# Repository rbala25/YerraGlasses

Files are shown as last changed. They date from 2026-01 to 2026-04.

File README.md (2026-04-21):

# YerraGlasses
 
Audio-augmented smart glasses that act as a wearable guide dog — real-time object detection converted to spatial audio feedback, all running on an ESP32-S3 tucked inside a glasses frame.
 
---
 
## Highlights
 
**Embedded ML Object Detection** — Neural network running on a **Luckfox RV1103 NPU** detects objects from live visual input and converts them into real-time auditory cues. Designed to assist blind and visually impaired users without any cloud dependency.
 
**Dual I2S Class-D Audio** — Two Class-D amplifiers driven over I2S deliver low-latency directional audio feedback. Custom DAC and speaker amplification stages built discrete, with 26-gauge wire crimped and routed by hand to fit the form factor.
 
**Space-Constrained PCB** — Custom board designed to fit inside a glasses frame. Integrates USB-C input, rail regulation, I2C sensor communication, and the full I2S audio pipeline — all in a footprint small enough to wear.
 
**Power System** — Robust battery management with USB-C charging, regulated power rails, and firmware-level power state detection to maximize battery life in a miniature form factor.
 
---
 
## Stack
 
| Layer | Tech |
|---|---|
| MCU | ESP32-S3 |
| Language | C, bare-metal |
| ML Inference | Luckfox RV1103 NPU (object detection) |
| Audio | Dual I2S Class-D amps + custom DAC |
| Communication | I2C |
| Power | USB-C + regulated rails + battery monitoring |
| Hardware | Custom PCB, 26-gauge hand-crimped wiring |

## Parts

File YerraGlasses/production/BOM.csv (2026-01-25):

Reference | Qty | Value | DNP | Exclude from BOM | Exclude from Board | Footprint | JLCPCB # | Mouser # | Mouser Link | Mouser Part Number
C1,C2,C15 | 3 | 4.7u |  |  |  | Capacitor_SMD:C_1206_3216Metric_Pad1.33x1.80mm_HandSolder | C513768 | 187-CL31A475KBHNNNE | https://www.mouser.com/ProductDetail/Samsung-Electro-Mechanics/CL31A475KBHNNNE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 | 187-CL31A475KBHNNNE
C3,C6,C7,C10,C11 | 5 | 100n |  |  |  | Capacitor_SMD:C_0603_1608Metric_Pad1.08x0.95mm_HandSolder | C14663 | 581-KAM15BR72A104KT | https://www.mouser.com/ProductDetail/KYOCERA-AVX/KAM15BR72A104KT?qs=Jm2GQyTW%2Fbivdeq3a3Ovhw%3D%3D | 581-KAM15BR72A104KT
C4,C8 | 2 | 10u |  |  |  | Capacitor_SMD:C_0805_2012Metric_Pad1.18x1.45mm_HandSolder | C440198 | 81-GRM21BR61H106KE3L | https://www.mouser.com/ProductDetail/Murata-Electronics/GRM21BR61H106KE43L?qs=lYGu3FyN48cBZlIduWKclg%3D%3D | 81-GRM21BR61H106KE3L
C5,C9 | 2 | 22u |  |  |  | Capacitor_SMD:C_0603_1608Metric_Pad1.08x0.95mm_HandSolder | C59461 | 963-A168BB5226MTNA01 | https://www.mouser.com/ProductDetail/TAIYO-YUDEN/MSASA168BB5226MTNA01?qs=efUn273yAhczomwMiufDyA%3D%3D | 963-A168BB5226MTNA01
D5 | 1 | SP3205-01ETG |  |  |  | 0_LHRE_Footprints:SP320501ETG | C19829542 | 576-SP3205-01ETG | https://www.mouser.com/ProductDetail/Littelfuse/SP3205-01ETG?qs=vHuUswq2%252BswfNhVD4WkB%252BQ%3D%3D | 576-SP3205-01ETG
D6 | 1 | UDD32C05L01 |  |  |  | Diode_SMD:D_SOD-323 | C78440 | 603-UDD32C05L01 | https://www.mouser.com/ProductDetail/YAGEO/UDD32C05L01?qs=0lSvoLzn4L8%252BwWZ0DjbM%2FA%3D%3D | 603-UDD32C05L01
D20 | 1 | D_Schottky |  |  |  | Diode_SMD:D_PowerDI-123 | C177023 | 621-DFLS160-F | https://www.mouser.com/ProductDetail/Diodes-Incorporated/DFLS160-7?qs=gAIB%252Bn6SvSQZOTFja6ZMPQ%3D%3D | 726-BAT60AE6327
D32,D33 | 2 | Green |  |  |  | Diode_SMD:D_0603_1608Metric_Pad1.05x0.95mm_HandSolder | C5246833 | 604-APT1608LZGCK | https://www.mouser.com/ProductDetail/Kingbright/APT1608LZGCK?qs=6oMev5NRZMFGFINT%2FafRYg%3D%3D | 604-APT1608LZGCK
F1,F2 | 2 | 1A |  |  |  | Fuse:Fuse_0603_1608Metric_Pad1.05x0.95mm_HandSolder | C136329 | 504-TR-0603HV1-R | https://www.mouser.com/ProductDetail/Eaton-Electronics/TR-0603HV1-R?qs=xZ%2FP%252Ba9zWqa2z3F2%252BP4ViA%3D%3D | 504-TR-0603HV1-R
H1,H2 | 2 | MountingHole |  | Excluded from BOM |  | MountingHole:MountingHole_2.2mm_M2_custom
J1,J2,J3,J4,J5 | 5 | Conn_01x02_Pin |  |  |  | Connector_JST:JST_PH_B2B-PH-K_1x02_P2.00mm_Vertical | C131337 | 306-B2BPHKSLFSNPP | https://www.mouser.com/ProductDetail/JST-Commercial/B2B-PH-K-SLFSN?qs=cdbOS8ANM9AlozzPlOt72g%3D%3D | 306-B2BPHKSLFSNPP
J11 | 1 | USB_C_Receptacle_USB2.0_16P |  |  |  | 0_LHRE_Footprints:USB-C_2.0_Receptacle | C2982555 | 640-USB4105-GF-A | https://www.mouser.com/ProductDetail/GCT/USB4105-GF-A?qs=KUoIvG%2F9IlY%2FMLlBMpStpA%3D%3D | 640-USB4105-GF-A
JP1 | 1 | SolderJumper_2_Open |  | Excluded from BOM |  | Jumper:SolderJumper-2_P1.3mm_Open_RoundedPad1.0x1.5mm
R1,R2,R45 | 3 | 10k |  |  |  | Resistor_SMD:R_0603_1608Metric_Pad0.98x0.95mm_HandSolder | C25804 | 71-CRCW0603-10K-E3 | https://www.mouser.com/ProductDetail/Vishay/CRCW060310K0FKEA?qs=pAO1Z172M84BVnhDjtnsoQ%3D%3D | 71-CRCW0603-10K-E3
R8,R35,R46,R48 | 4 | 5.1k |  |  |  | Resistor_SMD:R_0603_1608Metric_Pad0.98x0.95mm_HandSolder | C23186 | 71-CRCW0603-5.1K-E3 | https://www.mouser.com/ProductDetail/Vishay-Dale/CRCW06035K10FKEA?qs=pfqtYUWm1IVbeSxo5oKU9A%3D%3D | 71-CRCW0603-5.1K-E3
R9 | 1 | 100k |  |  |  | Resistor_SMD:R_0603_1608Metric_Pad0.98x0.95mm_HandSolder | C14675 | 603-RC0603FR-07100KL | https://www.mouser.com/ProductDetail/YAGEO/RC0603FR-07100KL?qs=e1ok2LiJcmaihem8Va5%2Fsw%3D%3D | 603-RC0603FR-07100KL
R22 | 1 | 22 |  |  |  | Resistor_SMD:R_0603_1608Metric_Pad0.98x0.95mm_HandSolder | C23345 | 71-CRCW0603-22-E3 | https://www.mouser.com/ProductDetail/Vishay-Dale/CRCW060322R0FKEA?qs=WV2t1o5hSQVzBsSjdimT7Q%3D%3D | 71-CRCW0603-22-E3
SW1 | 1 | SW_SPDT |  |  |  | Button_Switch_SMD:SW_SPDT_PCM12 | C319020 | 611-PCM12SMTBR | https://www.mouser.com/ProductDetail/CK/PCM12SMTBR?qs=By6Nw2ByBD1OEOnWcdZb2g%3D%3D | 611-PCM12SMTBR
TP1 | 1 | bootloader |  | Excluded from BOM |  | TestPoint:TestPoint_Pad_1.0x1.0mm
TP2 | 1 | gndBootloader |  | Excluded from BOM |  | TestPoint:TestPoint_Pad_1.0x1.0mm
U1 | 1 | ESP32-S3-WROOM-1 |  |  |  | RF_Module:ESP32-S3-WROOM-1 | C2913199 | 356-ESP32S3WROOM1N16 | https://www.mouser.com/ProductDetail/Espressif-Systems/ESP32-S3-WROOM-1-N16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 | 356-ESP32S3WROOM1N16
U2,U3 | 2 | MAX98357A |  |  |  | Package_DFN_QFN:TQFN-16-1EP_3x3mm_P0.5mm_EP1.23x1.23mm | C910544 | 700-MAX98357AETE+T | https://www.mouser.com/ProductDetail/Analog-Devices-Maxim-Integrated/MAX98357AETE%2bT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 | 700-MAX98357AETE+T
U4 | 1 | RT9013-33GB |  |  |  | Package_TO_SOT_SMD:SOT-23-5 | C47773 | 835-RT9013-33GB | https://www.mouser.com/ProductDetail/Richtek/RT9013-33GB?qs=amGC7iS6iy%2FHaDkSgZH71g%3D%3D | 835-RT9013-33GB
U6 | 1 | R-78E5.0-1.0 |  |  |  | Converter_DCDC:Converter_DCDC_RECOM_R-78E-0.5_THT | C22371890 | 919-R-78E5.0-1.0 | https://www.mouser.com/ProductDetail/RECOM-Power/R-78E5.0-1.0?qs=T0XSgvH75d4EsZCU9I5HVA%3D%3D | 919-R-78E5.0-1.0

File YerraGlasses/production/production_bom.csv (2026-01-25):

Designator | Footprint | Quantity | Value | LCSC Part #
C1, C15, C2 | 1206 | 3 | 4.7u
C10, C11, C3, C6, C7 | 0603 | 5 | 100n
C4, C8 | 0805 | 2 | 10u
C5, C9 | 0603 | 2 | 22u
D20 | D_PowerDI-123 | 1 | D_Schottky
D32, D33 | 0603 | 2 | Green
D5 | SP320501ETG | 1 | SP3205-01ETG
D6 | D_SOD-323 | 1 | UDD32C05L01
F1, F2 | 0603 | 2 | 1A
J1, J2, J3, J4, J5 | JST_PH_B2B-PH-K_1x02_P2.00mm_Vertical | 5 | Conn_01x02_Pin
J11 | USB-C_2.0_Receptacle | 1 | USB_C_Receptacle_USB2.0_16P
R1, R2, R45 | 0603 | 3 | 10k
R22 | 0603 | 1 | 22
R35, R46, R48, R8 | 0603 | 4 | 5.1k
R9 | 0603 | 1 | 100k
SW1 | SW_SPDT_PCM12 | 1 | SW_SPDT
U1 | ESP32-S3-WROOM-1 | 1 | ESP32-S3-WROOM-1
U2, U3 | TQFN-16-1EP_3x3mm_P0.5mm_EP1.23x1.23mm | 2 | MAX98357A
U4 | SOT-23-5 | 1 | RT9013-33GB
U6 | Converter_DCDC_RECOM_R-78E-0.5_THT | 1 | R-78E5.0-1.0

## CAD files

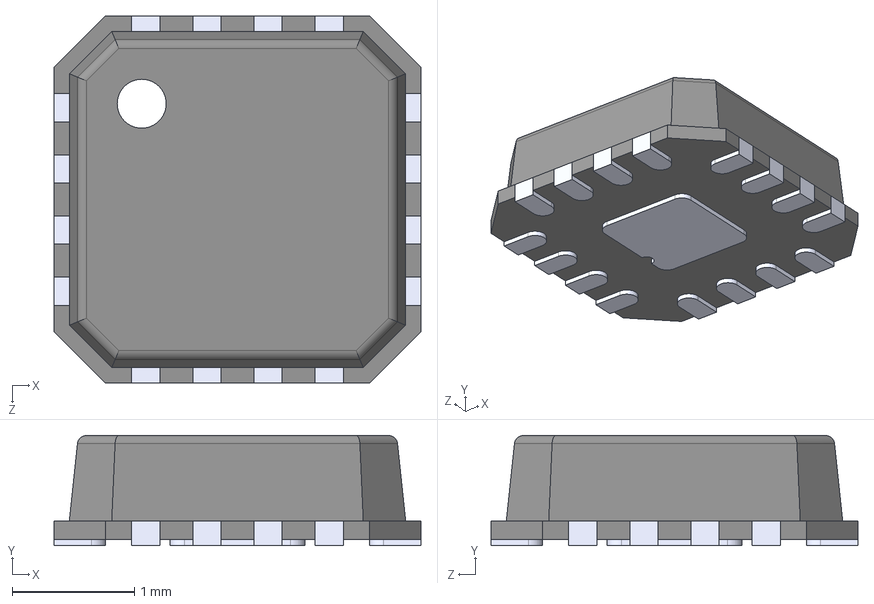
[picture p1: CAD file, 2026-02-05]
CAD/QFN50P300X300X80-17N.step
3.00 x 0.9 x 3.00 mm

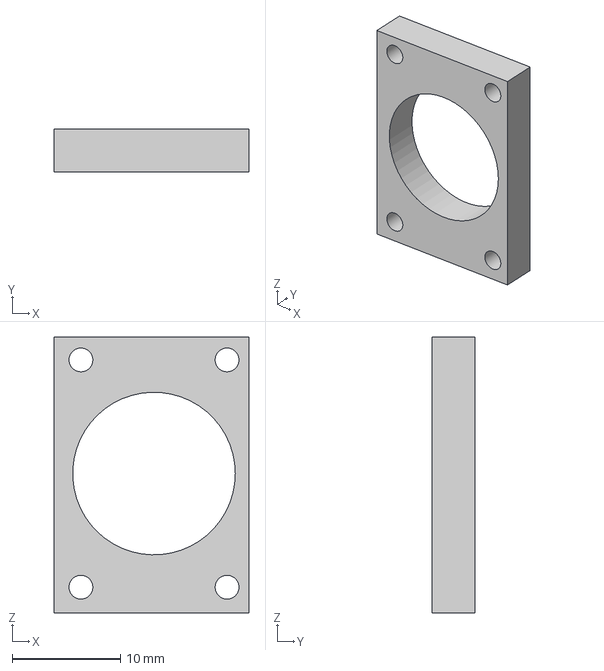
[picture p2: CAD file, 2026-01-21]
CAD/PrintableCameraMount.step
18.0 x 4.00 x 25.5 mm

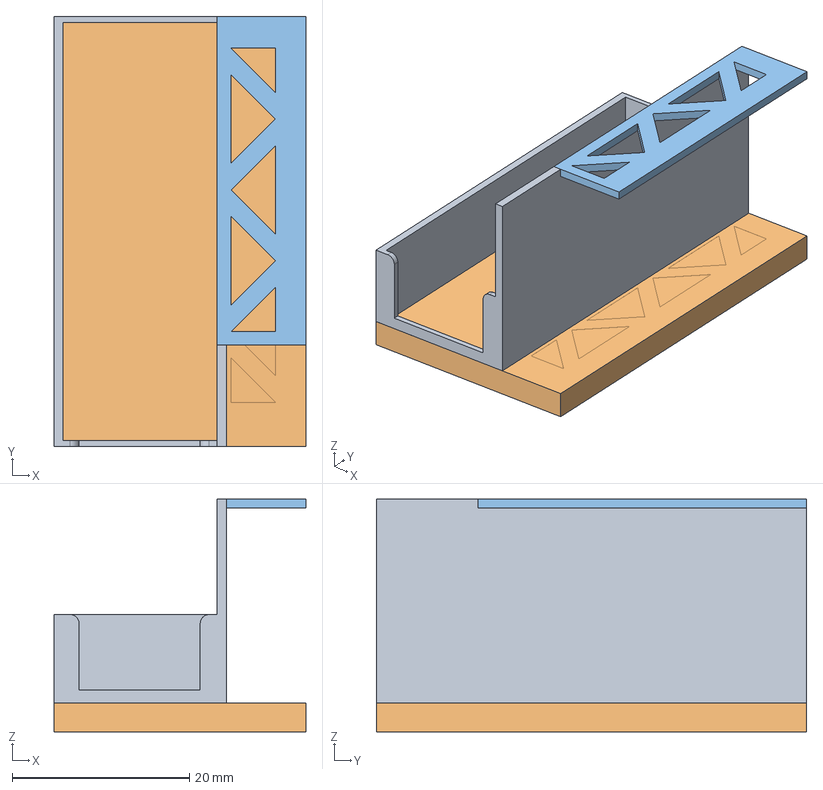
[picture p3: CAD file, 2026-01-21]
CAD/PrintableBatteryMount.step
28.4 x 48.6 x 26.3 mm

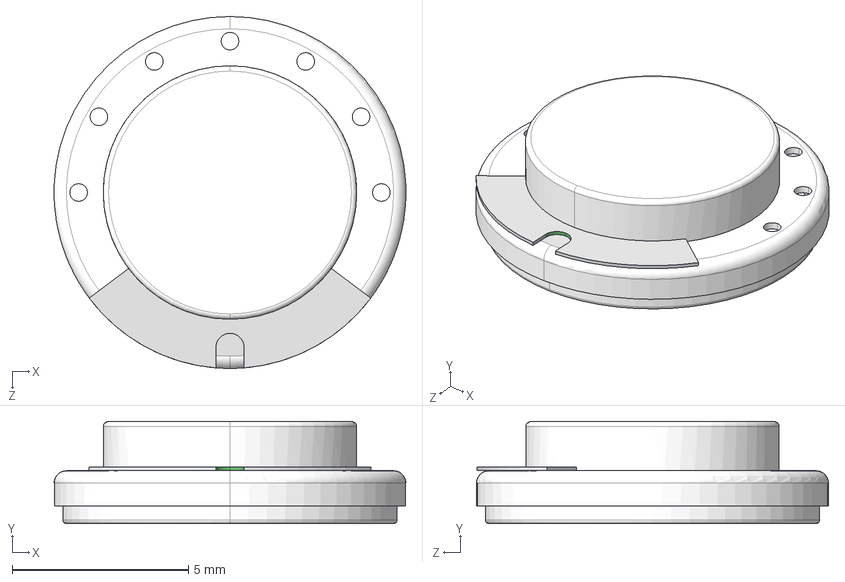
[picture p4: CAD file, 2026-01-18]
CAD/Same_Sky_CDM-10008.step
9.99 x 2.90 x 10.0 mm

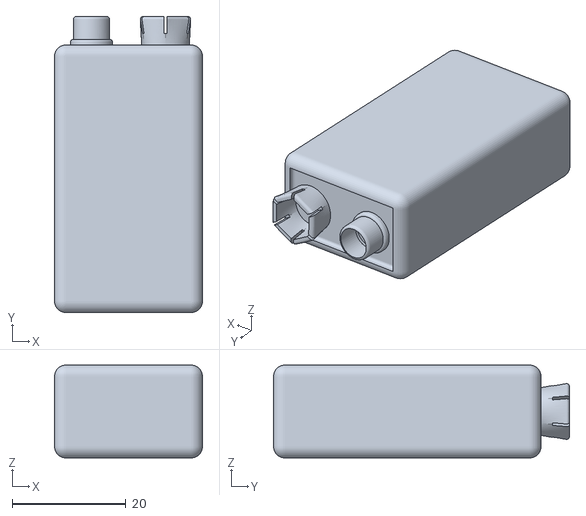
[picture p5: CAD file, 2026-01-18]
CAD/9V BATTRAY.STL
26.0 x 52.0 x 16.3

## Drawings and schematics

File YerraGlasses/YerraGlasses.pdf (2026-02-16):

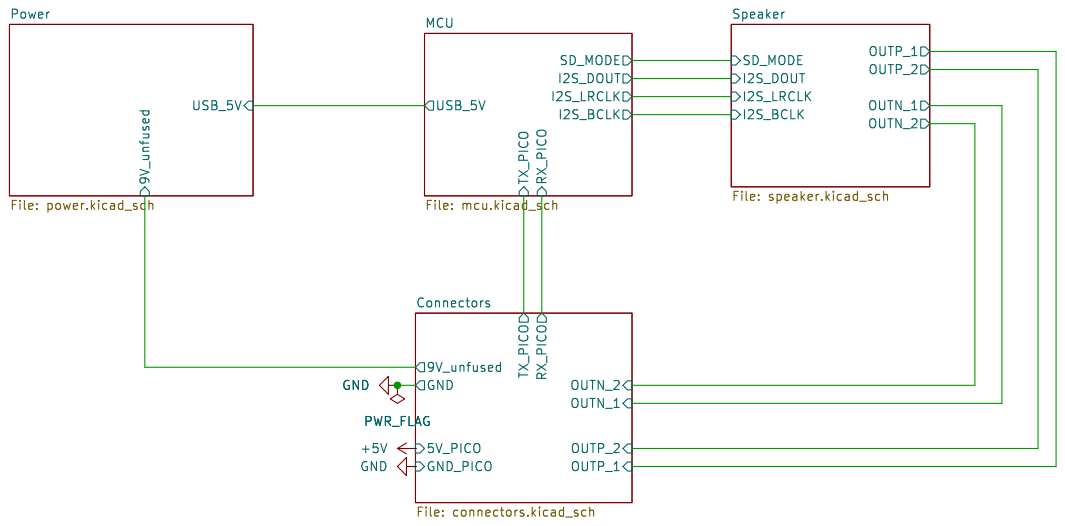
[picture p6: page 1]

Speaker File: speaker.kicad_sch GND
I2S_BCLK MCU

Id: 1/5 Title: File: YerraGlasses.kicad_sch Sheet: /

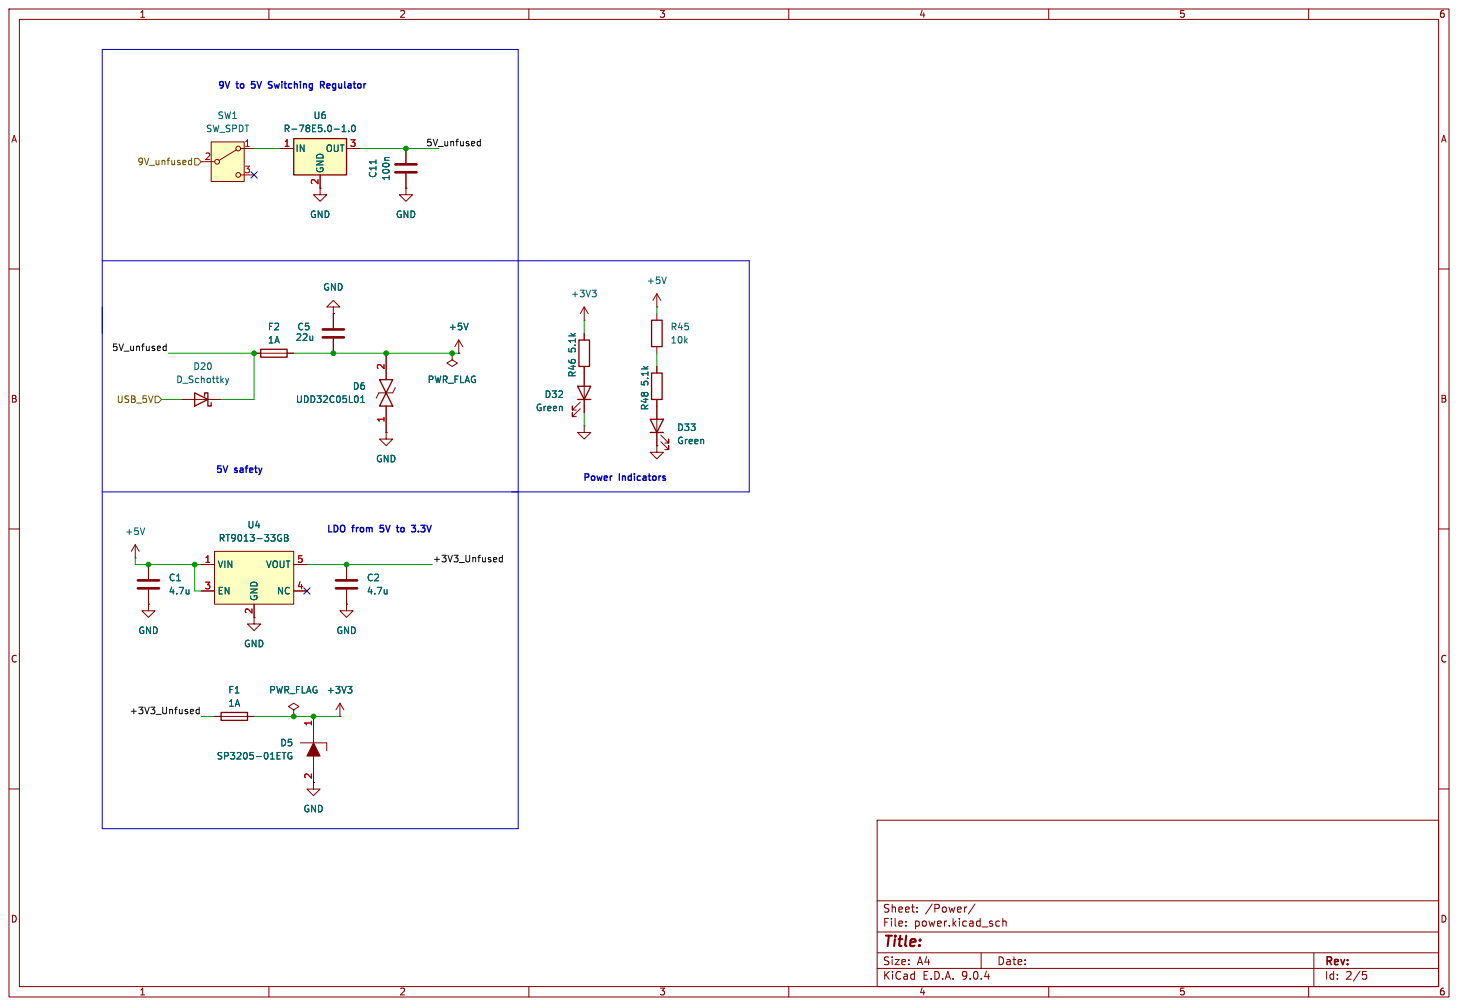
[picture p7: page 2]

Id: 2/5 Title: File: power.kicad_sch Sheet: /Power/

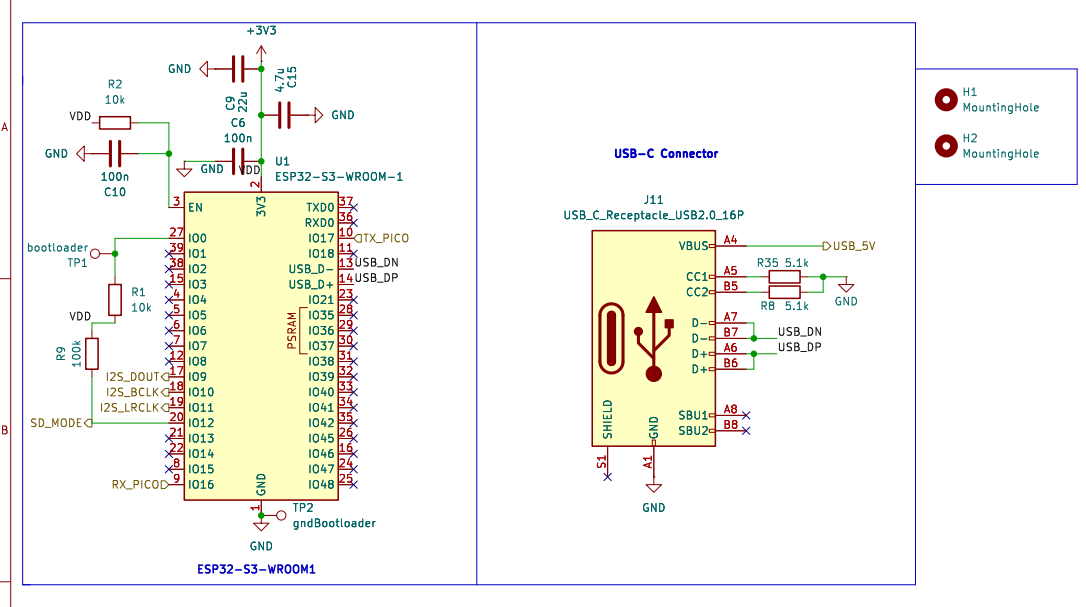
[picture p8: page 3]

Id: 3/5 Title: File: mcu.kicad_sch Sheet: /MCU/

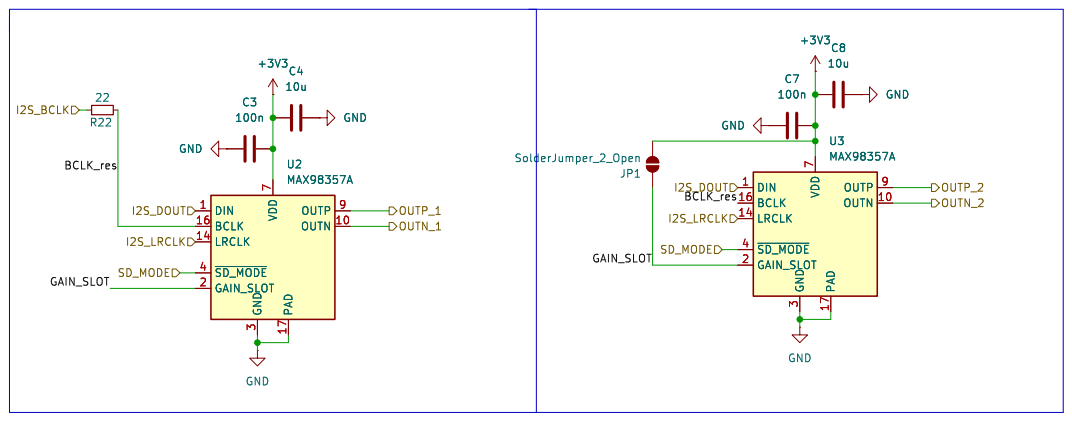
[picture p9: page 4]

7 PAD 17 OUTP 9 OUTN 10 U2 MAX98357AGND GND

7 PAD 17 OUTP 9 OUTN 10 U3 MAX98357A GND

Id: 4/5 Title: File: speaker.kicad_sch Sheet: /Speaker/

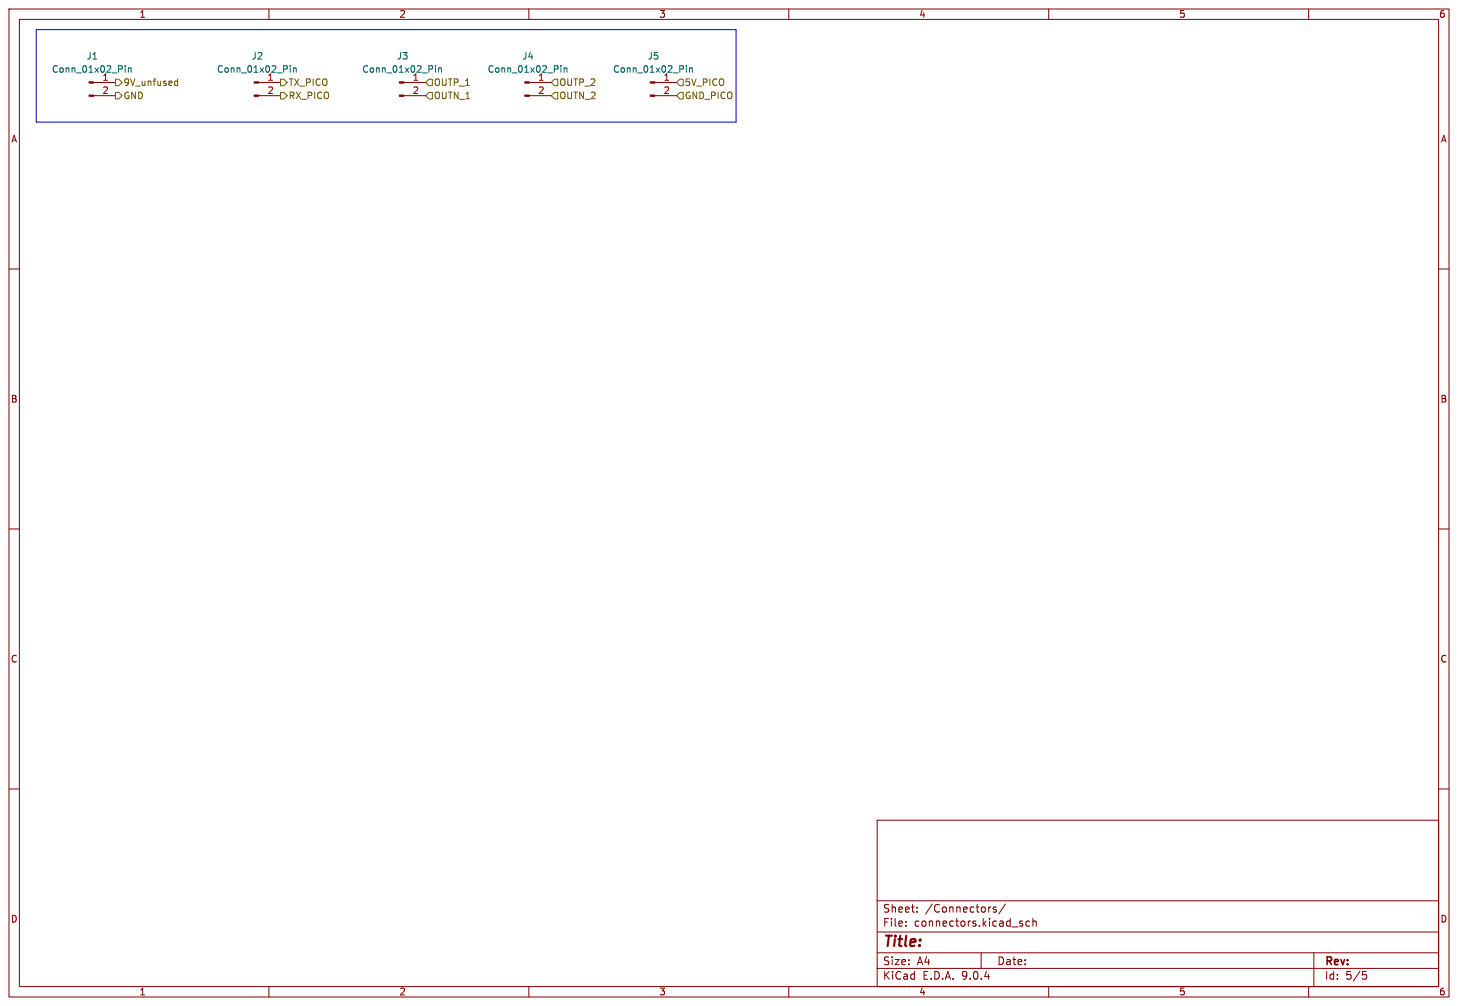
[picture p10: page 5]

Id: 5/5 Title: File: connectors.kicad_sch Sheet: /Connectors/

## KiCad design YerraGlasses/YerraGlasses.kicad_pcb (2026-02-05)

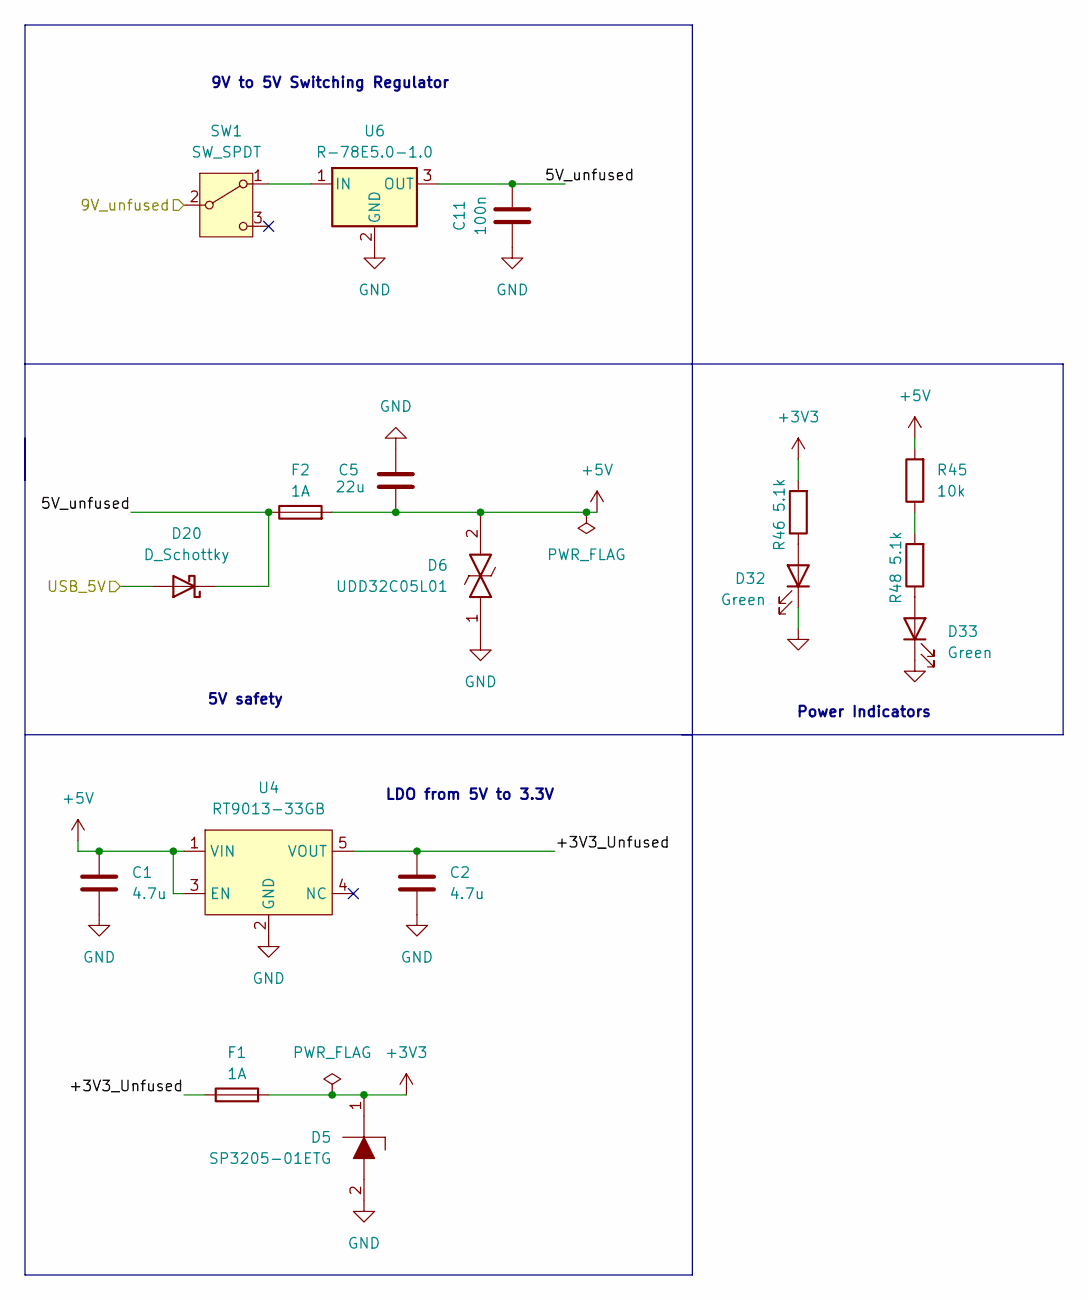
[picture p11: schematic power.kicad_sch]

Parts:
C1, C2: 4.7u; C_1206_3216Metric_Pad1.33x1.80mm_HandSolder; Mouser # 187-CL31A475KBHNNNE
C5: 22u; C_0603_1608Metric_Pad1.08x0.95mm_HandSolder; Mouser # 963-A168BB5226MTNA01
C11: 100n; C_0603_1608Metric_Pad1.08x0.95mm_HandSolder; Mouser # 581-KAM15BR72A104KT
D5: SP3205-01ETG; SP320501ETG; Mouser # 576-SP3205-01ETG
D6: UDD32C05L01; D_SOD-323; Mouser # 603-UDD32C05L01
D20: D_Schottky; D_PowerDI-123; Mouser # 621-DFLS160-F
D32, D33: Green; D_0603_1608Metric_Pad1.05x0.95mm_HandSolder; Mouser # 604-APT1608LZGCK
F1, F2: 1A; Fuse_0603_1608Metric_Pad1.05x0.95mm_HandSolder; Mouser # 504-TR-0603HV1-R
R45: 10k; R_0603_1608Metric_Pad0.98x0.95mm_HandSolder; Mouser # 71-CRCW0603-10K-E3
R46, R48: 5.1k; R_0603_1608Metric_Pad0.98x0.95mm_HandSolder; Mouser # 71-CRCW0603-5.1K-E3
SW1: SW_SPDT; SW_SPDT_PCM12; Mouser # 611-PCM12SMTBR
U4: RT9013-33GB; SOT-23-5; Mouser # 835-RT9013-33GB
U6: R-78E5.0-1.0; Converter_DCDC_RECOM_R-78E-0.5_THT; Mouser # 919-R-78E5.0-1.0; JLCPCB # C22371890

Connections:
+3V3: D5.1, F1.2, R46.2; also elsewhere on the board
+5V: C1.1, C5.1, D6.2, F2.2, R45.2, U4.1 (VIN), U4.3 (EN); also elsewhere on the board
/Connectors/9V_unfused: SW1.2 (B); also elsewhere on the board
/MCU/USB_5V: D20.2 (A); also elsewhere on the board
/Power/5V_unfused: C11.2, D20.1 (K), F2.1, U6.3 (OUT)
/Power/+3V3_Unfused: C2.1, F1.1, U4.5 (VOUT)
GND: C1.2, C2.2, C5.2, C11.1, D5.2, D6.1, D32.1 (K), D33.1 (K), U4.2 (GND), U6.2 (GND); also elsewhere on the board
unnamed: D32.2 (A), R46.1
unnamed: D33.2 (A), R48.1
unnamed: R45.1, R48.2
unnamed: SW1.1 (A), U6.1 (IN)

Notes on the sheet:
Power Indicators
LDO from 5V to 3.3V
5V safety
9V to 5V Switching Regulator

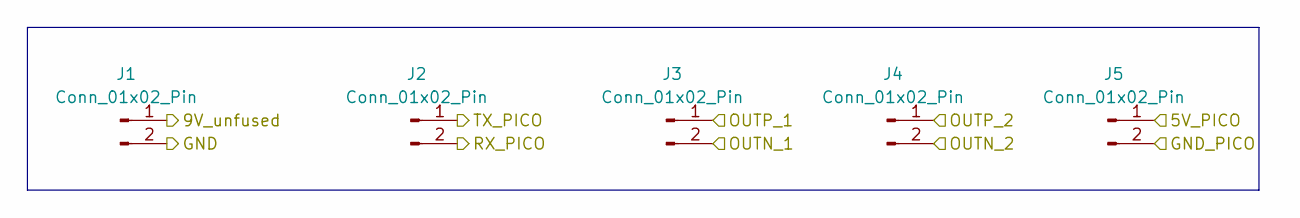
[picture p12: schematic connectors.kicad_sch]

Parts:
J1, J2, J3, J4, J5: Conn_01x02_Pin; JST_PH_B2B-PH-K_1x02_P2.00mm_Vertical; Mouser # 306-B2BPHKSLFSNPP; JLCPCB # C131337

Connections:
+5V: J5.1; also elsewhere on the board
/Connectors/9V_unfused: J1.1; also elsewhere on the board
/Connectors/OUTN_1: J3.2; also elsewhere on the board
/Connectors/OUTN_2: J4.2; also elsewhere on the board
/Connectors/OUTP_1: J3.1; also elsewhere on the board
/Connectors/OUTP_2: J4.1; also elsewhere on the board
/Connectors/RX_PICO: J2.2; also elsewhere on the board
/Connectors/TX_PICO: J2.1; also elsewhere on the board
GND: J1.2, J5.2; also elsewhere on the board

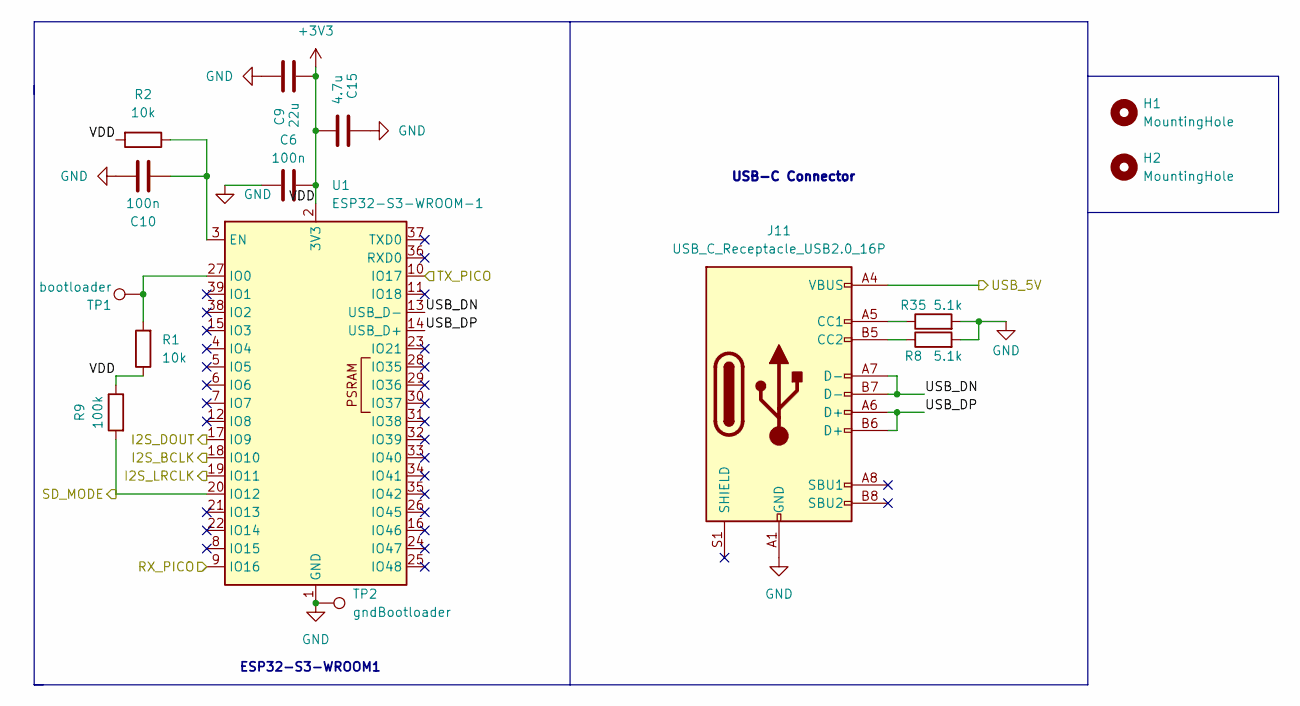
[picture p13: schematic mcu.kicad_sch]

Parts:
C6, C10: 100n; C_0603_1608Metric_Pad1.08x0.95mm_HandSolder; Mouser # 581-KAM15BR72A104KT
C9: 22u; C_0603_1608Metric_Pad1.08x0.95mm_HandSolder; Mouser # 963-A168BB5226MTNA01
C15: 4.7u; C_1206_3216Metric_Pad1.33x1.80mm_HandSolder; Mouser # 187-CL31A475KBHNNNE
H1, H2: MountingHole; MountingHole_2.2mm_M2_custom
J11: USB_C_Receptacle_USB2.0_16P; USB-C_2.0_Receptacle; Mouser # 640-USB4105-GF-A
R1, R2: 10k; R_0603_1608Metric_Pad0.98x0.95mm_HandSolder; Mouser # 71-CRCW0603-10K-E3
R8, R35: 5.1k; R_0603_1608Metric_Pad0.98x0.95mm_HandSolder; Mouser # 71-CRCW0603-5.1K-E3
R9: 100k; R_0603_1608Metric_Pad0.98x0.95mm_HandSolder; Mouser # 603-RC0603FR-07100KL
TP1: bootloader; TestPoint_Pad_1.0x1.0mm
TP2: gndBootloader; TestPoint_Pad_1.0x1.0mm
U1: ESP32-S3-WROOM-1; Mouser # 356-ESP32S3WROOM1N16; JLCPCB # C2913199

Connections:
+3V3: C6.2, C9.1, C15.1, R1.1, R2.2, R9.1, U1.2 (3V3); also elsewhere on the board
/Connectors/RX_PICO: U1.9 (IO16); also elsewhere on the board
/Connectors/TX_PICO: U1.10 (IO17); also elsewhere on the board
/MCU/I2S_BCLK: U1.18 (IO10); also elsewhere on the board
/MCU/I2S_DOUT: U1.17 (IO9); also elsewhere on the board
/MCU/I2S_LRCLK: U1.19 (IO11); also elsewhere on the board
/MCU/SD_MODE: R9.2, U1.20 (IO12); also elsewhere on the board
/MCU/USB_5V: J11.A4 (VBUS), J11.A9 (VBUS), J11.B4 (VBUS), J11.B9 (VBUS); also elsewhere on the board
/MCU/USB_DN: J11.A7 (D-), J11.B7 (D-), U1.13 (USB_D-)
/MCU/USB_DP: J11.A6 (D+), J11.B6 (D+), U1.14 (USB_D+)
GND: C6.1, C9.2, C10.2, C15.2, J11.A1 (GND), J11.A12 (GND), J11.B1 (GND), J11.B12 (GND), R8.2, R35.2, TP2.1, U1.1 (GND), U1.40 (GND), U1.41 (GND); also elsewhere on the board
unnamed: J11.A5 (CC1), R35.1
unnamed: J11.B5 (CC2), R8.1
unnamed: C10.1, R2.1, U1.3 (EN)
unnamed: R1.2, TP1.1, U1.27 (IO0)

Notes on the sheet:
ESP32-S3-WROOM1
USB-C Connector

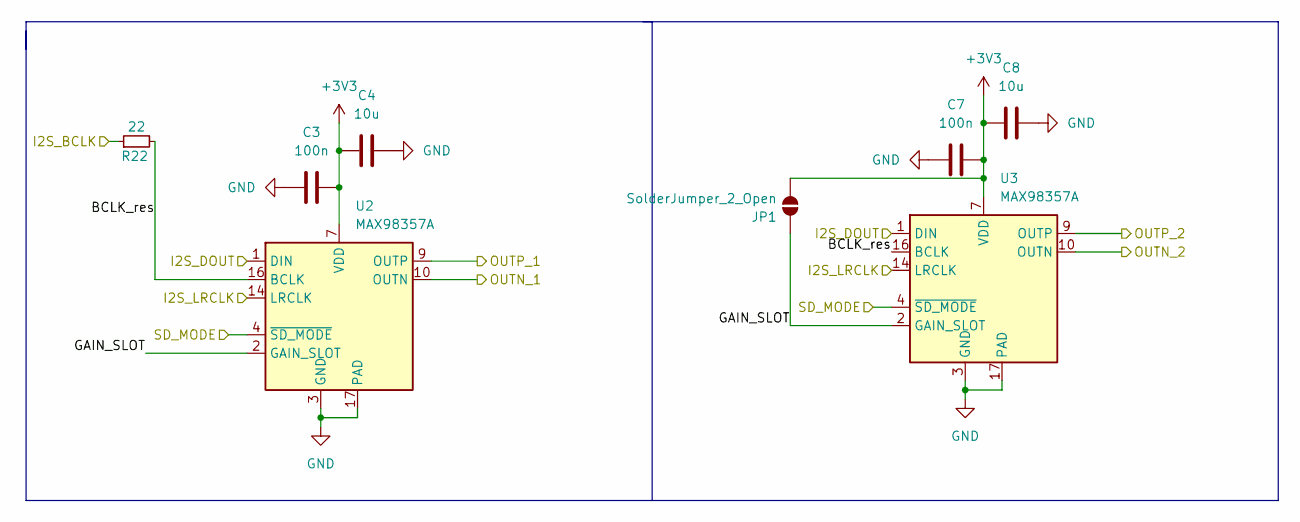
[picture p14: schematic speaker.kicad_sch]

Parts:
C3, C7: 100n; C_0603_1608Metric_Pad1.08x0.95mm_HandSolder; Mouser # 581-KAM15BR72A104KT
C4, C8: 10u; C_0805_2012Metric_Pad1.18x1.45mm_HandSolder; Mouser # 81-GRM21BR61H106KE3L
JP1: SolderJumper_2_Open; SolderJumper-2_P1.3mm_Open_RoundedPad1.0x1.5mm
R22: 22; R_0603_1608Metric_Pad0.98x0.95mm_HandSolder; Mouser # 71-CRCW0603-22-E3
U2, U3: MAX98357A; TQFN-16-1EP_3x3mm_P0.5mm_EP1.23x1.23mm; Mouser # 700-MAX98357AETE+T; JLCPCB # C910544

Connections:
+3V3: C3.2, C4.2, C7.2, C8.2, JP1.1 (A), U2.7 (VDD), U2.8 (VDD), U3.7 (VDD), U3.8 (VDD); also elsewhere on the board
/Connectors/OUTN_1: U2.10 (OUTN); also elsewhere on the board
/Connectors/OUTN_2: U3.10 (OUTN); also elsewhere on the board
/Connectors/OUTP_1: U2.9 (OUTP); also elsewhere on the board
/Connectors/OUTP_2: U3.9 (OUTP); also elsewhere on the board
/MCU/I2S_BCLK: R22.1; also elsewhere on the board
/MCU/I2S_DOUT: U2.1 (DIN), U3.1 (DIN); also elsewhere on the board
/MCU/I2S_LRCLK: U2.14 (LRCLK), U3.14 (LRCLK); also elsewhere on the board
/MCU/SD_MODE: U2.4 (~SD_MODE), U3.4 (~SD_MODE); also elsewhere on the board
/Speaker/BCLK_res: R22.2, U2.16 (BCLK), U3.16 (BCLK)
/Speaker/GAIN_SLOT: JP1.2 (B), U2.2 (GAIN_SLOT), U3.2 (GAIN_SLOT)
GND: C3.1, C4.1, C7.1, C8.1, U2.3 (GND), U2.11 (GND), U2.15 (GND), U2.17 (PAD), U3.3 (GND), U3.11 (GND), U3.15 (GND), U3.17 (PAD); also elsewhere on the board

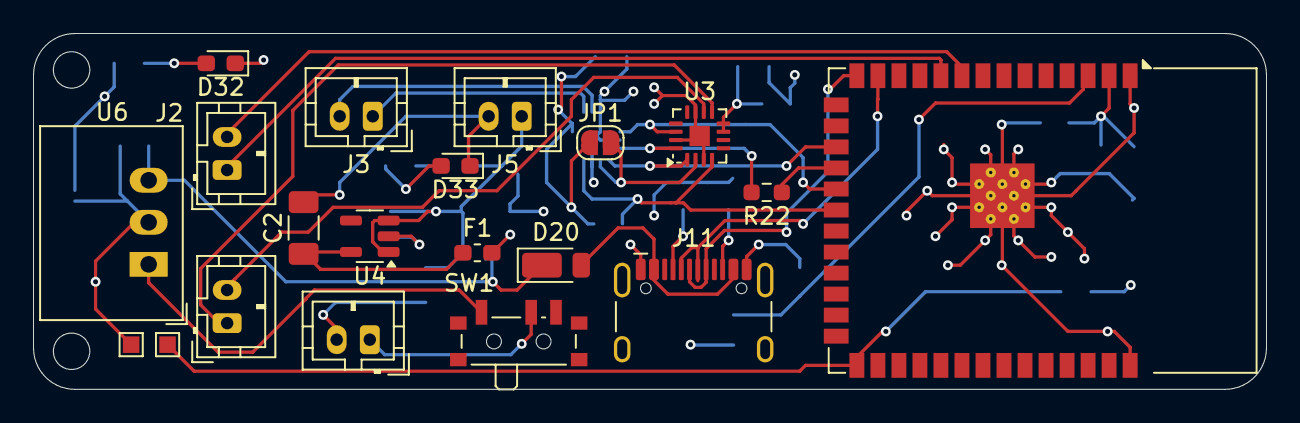
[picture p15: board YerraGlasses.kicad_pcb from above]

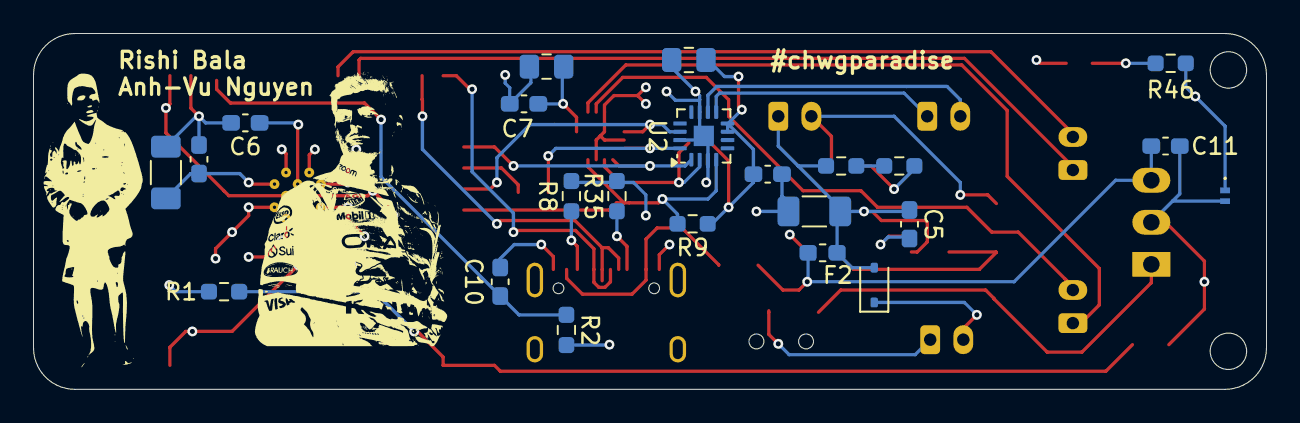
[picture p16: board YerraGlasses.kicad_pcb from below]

Board: 4 copper layers, 74.5 x 21.5 mm, 45 parts (23 on the bottom side), 29 nets.

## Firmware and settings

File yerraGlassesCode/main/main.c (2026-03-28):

#include <stdio.h>
#include <string.h>
#include <stdlib.h>
#include <stdbool.h>

#include "freertos/FreeRTOS.h"
#include "freertos/task.h"
#include "freertos/queue.h"

#include "driver/gpio.h"
#include "driver/i2s_std.h"
#include "driver/uart.h"

#include "esp_log.h"
// #include "esp_system.h"
#include "esp_spiffs.h"
// #include "esp_vfs.h"

#define TAG "YERRA"

/* ==========label map========*/

typedef struct
{
    const char *label;
    const char *file;
} label_map_t;

static const label_map_t label_map[] = {

    {"person", "/spiffs/person.wav"},
    {"bicycle", "/spiffs/bicycle.wav"},
    {"car", "/spiffs/car.wav"},
    {"motorcycle", "/spiffs/motorcycle.wav"},
    {"airplane", "/spiffs/airplane.wav"},
    {"bus", "/spiffs/bus.wav"},
    {"train", "/spiffs/train.wav"},
    {"truck", "/spiffs/truck.wav"},
    {"boat", "/spiffs/boat.wav"},
    {"traffic light", "/spiffs/traffic_light.wav"},
    {"fire hydrant", "/spiffs/fire_hydrant.wav"},
    {"stop sign", "/spiffs/stop_sign.wav"},
    {"parking meter", "/spiffs/parking_meter.wav"},
    {"bench", "/spiffs/bench.wav"},
    {"bird", "/spiffs/bird.wav"},
    {"cat", "/spiffs/cat.wav"},
    {"dog", "/spiffs/dog.wav"},
    {"horse", "/spiffs/horse.wav"},
    {"sheep", "/spiffs/sheep.wav"},
    {"cow", "/spiffs/cow.wav"},
    {"elephant", "/spiffs/elephant.wav"},
    {"bear", "/spiffs/bear.wav"},
    {"zebra", "/spiffs/zebra.wav"},
    {"giraffe", "/spiffs/giraffe.wav"},
    {"backpack", "/spiffs/backpack.wav"},
    {"umbrella", "/spiffs/umbrella.wav"},
    {"handbag", "/spiffs/handbag.wav"},
    {"tie", "/spiffs/tie.wav"},
    {"suitcase", "/spiffs/suitcase.wav"},
    {"frisbee", "/spiffs/frisbee.wav"},
    {"skis", "/spiffs/skis.wav"},
    {"snowboard", "/spiffs/snowboard.wav"},
    {"sports ball", "/spiffs/sports_ball.wav"},
    {"kite", "/spiffs/kite.wav"},
    {"baseball bat", "/spiffs/baseball_bat.wav"},
    {"baseball glove", "/spiffs/baseball_glove.wav"},
    {"skateboard", "/spiffs/skateboard.wav"},
    {"surfboard", "/spiffs/surfboard.wav"},
    {"tennis racket", "/spiffs/tennis_racket.wav"},
    {"bottle", "/spiffs/bottle.wav"},
    {"wine glass", "/spiffs/wine_glass.wav"},
    {"cup", "/spiffs/cup.wav"},
    {"fork", "/spiffs/fork.wav"},
    {"knife", "/spiffs/knife.wav"},
    {"spoon", "/spiffs/spoon.wav"},
    {"bowl", "/spiffs/bowl.wav"},
    {"banana", "/spiffs/banana.wav"},
    {"apple", "/spiffs/apple.wav"},
    {"sandwich", "/spiffs/sandwich.wav"},
    {"orange", "/spiffs/orange.wav"},
    {"brocolli", "/spiffs/brocolli.wav"},
    {"carrot", "/spiffs/carrot.wav"},
    {"hot dog", "/spiffs/hot_dog.wav"},
    {"pizza", "/spiffs/pizza.wav"},
    {"donut", "/spiffs/donut.wav"},
    {"cake", "/spiffs/cake.wav"},
    {"chair", "/spiffs/chair.wav"},
    {"couch", "/spiffs/couch.wav"},
    {"potted plant", "/spiffs/potted_plant.wav"},
    {"bed", "/spiffs/bed.wav"},
    {"dining table", "/spiffs/dining_table.wav"},
    {"toilet", "/spiffs/toilet.wav"},
    {"tv", "/spiffs/tv.wav"},
    {"laptop", "/spiffs/laptop.wav"},
    {"mouse", "/spiffs/mouse.wav"},
    {"remote", "/spiffs/remote.wav"},
    {"keyboard", "/spiffs/keyboard.wav"},
    {"cell phone", "/spiffs/cell_phone.wav"},
    {"microwave", "/spiffs/microwave.wav"},
    {"oven", "/spiffs/oven.wav"},
    {"toaster", "/spiffs/toaster.wav"},
    {"sink", "/spiffs/sink.wav"},
    {"refrigerator", "/spiffs/refrigerator.wav"},
    {"book", "/spiffs/book.wav"},
    {"clock", "/spiffs/clock.wav"},
    {"vase", "/spiffs/vase.wav"},
    {"scissors", "/spiffs/scissors.wav"},
    {"teddy bear", "/spiffs/teddy_bear.wav"},
    {"hair drier", "/spiffs/hair_drier.wav"},
    {"toothbrush", "/spiffs/toothbrush.wav"}

};

#define NUM_LABELS (sizeof(label_map) / sizeof(label_map[0]))

/* ================= UART ================= */

#define UART_PORT   UART_NUM_1
#define UART_RX_PIN 4
#define UART_TX_PIN 5
#define UART_BAUD   115200
#define UART_BUF_SZ 256

/* ================= i2s ================= */
#define I2S_BCLK_PIN 10
#define I2S_LRCLK_PIN 11
#define I2S_DATA_PIN 9
#define AMP_EN_PIN 12

static i2s_chan_handle_t i2s_tx_chan;

/* ================= audio Queue ================= */
static QueueHandle_t audio_queue;
static volatile bool speaking = false;

/* ================= amp ================= */

static void init_amp(void)
{
    gpio_config_t io_cfg = {
        .pin_bit_mask = 1ULL << AMP_EN_PIN,
        .mode = GPIO_MODE_OUTPUT,
    };
    gpio_config(&io_cfg);
    gpio_set_level(AMP_EN_PIN, 1);
}

/* ================= UART config ================= */

static void init_uart(void)
{
    uart_config_t conf = {
        .baud_rate  = UART_BAUD,
        .data_bits  = UART_DATA_8_BITS,
        .parity     = UART_PARITY_DISABLE,
        .stop_bits  = UART_STOP_BITS_1,
        .flow_ctrl  = UART_HW_FLOWCTRL_DISABLE,
    };

    ESP_ERROR_CHECK(uart_param_config(UART_PORT, &conf));
    ESP_ERROR_CHECK(uart_set_pin(UART_PORT, UART_TX_PIN, UART_RX_PIN,
                                 UART_PIN_NO_CHANGE, UART_PIN_NO_CHANGE));
    ESP_ERROR_CHECK(uart_driver_install(UART_PORT, UART_BUF_SZ * 2, 0, 0, NULL, 0));

    ESP_LOGI(TAG, "UART initialized at %d baud", UART_BAUD);
}

/* ================= i2s ================= */

static void init_i2s(void)
{
    i2s_chan_config_t chan_cfg =
        I2S_CHANNEL_DEFAULT_CONFIG(I2S_NUM_0, I2S_ROLE_MASTER);

    chan_cfg.dma_desc_num = 4;
    chan_cfg.dma_frame_num = 240;

    ESP_ERROR_CHECK(i2s_new_channel(&chan_cfg, &i2s_tx_chan, NULL));

    i2s_std_config_t std_cfg = {
        .clk_cfg = I2S_STD_CLK_DEFAULT_CONFIG(16000),
        .slot_cfg = I2S_STD_MSB_SLOT_DEFAULT_CONFIG(
            I2S_DATA_BIT_WIDTH_16BIT,
            I2S_SLOT_MODE_MONO),
        .gpio_cfg = {
            .mclk = I2S_GPIO_UNUSED,
            .bclk = I2S_BCLK_PIN,
            .ws = I2S_LRCLK_PIN,
            .dout = I2S_DATA_PIN,
            .din = I2S_GPIO_UNUSED,
        },
    };

    ESP_ERROR_CHECK(i2s_channel_init_std_mode(i2s_tx_chan, &std_cfg));
    ESP_ERROR_CHECK(i2s_channel_enable(i2s_tx_chan));
}

/* ================= spiffs ================= */

static void init_spiffs(void)
{
    esp_vfs_spiffs_conf_t conf = {
        .base_path = "/spiffs",
        .partition_label = NULL,
        .max_files = 5,
        .format_if_mount_failed = true};

    ESP_ERROR_CHECK(esp_vfs_spiffs_register(&conf));
    ESP_LOGI(TAG, "SPIFFS mounted");
}

/* ================= wav player ================= */

static void play_wav(const char *path)
{
    FILE *f = fopen(path, "rb");
    if (!f)
    {
        ESP_LOGE(TAG, "Failed to open %s", path);
        return;
    }

    uint8_t buf[1];
    uint8_t match[4] = {'d', 'a', 't', 'a'};
    int matched = 0;
    long data_offset = -1;

    for (int i = 0; i < 512; i++)
    {
        if (fread(buf, 1, 1, f) != 1) 
        {
            ESP_LOGE(TAG, "fread failed at byte %d", i);
            break;
        }
        if (buf[0] == match[matched])
            matched++;
        else
            matched = 0;
        if (matched == 4)
        {
            data_offset = ftell(f) + 4;
            ESP_LOGI(TAG, "Found data chunk at offset %ld", data_offset);
            break;
        }
    }

    if (data_offset < 0)
    {
        ESP_LOGE(TAG, "No data chunk found in %s", path);
        fclose(f);
        return;
    }

    int seek_ret = fseek(f, data_offset, SEEK_SET);
    ESP_LOGI(TAG, "fseek to %ld returned %d", data_offset, seek_ret);

    int16_t samples[512];
    size_t bytes_written;
    int chunk_count = 0;

    while (1)
    {
        size_t samples_read = fread(samples, sizeof(int16_t), 512, f);
        if (samples_read == 0)
            break;
        chunk_count++;
        i2s_channel_write(i2s_tx_chan, samples, samples_read * sizeof(int16_t),
                          &bytes_written, portMAX_DELAY);
    }

    ESP_LOGI(TAG, "Played %d chunks", chunk_count);
    fclose(f);
}

/* ================= audio task ================= */

static void audio_task(void *arg)
{
    char filepath[64];

    while (1)
    {
        if (xQueueReceive(audio_queue, filepath, portMAX_DELAY))
        {
            speaking = true;
            ESP_LOGI(TAG, "Speaking: %s", filepath);
            play_wav(filepath);
            speaking = false;
        }
    }
}

// static void audio_task(void *arg)
// {
//     while (1)
//     {
//         speaking = true;
//         ESP_LOGI(TAG, "Looping person.wav");
//         play_wav("/spiffs/person.wav");
//     }
// }

/* ================= UART task ================= */

/* ================= UART task ================= */

static void uart_task(void *arg)
{
    uint8_t buf[UART_BUF_SZ];
    char line[UART_BUF_SZ];
    int line_pos = 0;

    while (1)
    {
        int len = uart_read_bytes(UART_PORT, buf, UART_BUF_SZ - 1, pdMS_TO_TICKS(10));

        for (int i = 0; i < len; i++)
        {
            if (buf[i] == '\n')
            {
                line[line_pos] = 0;
                line_pos = 0;

                char label[32];
                int x1, y1, x2, y2;
                float prob;

                if (sscanf(line, "%31[^@]@ (%d %d %d %d) %f",
                           label, &x1, &y1, &x2, &y2, &prob) == 6)
                {
                    // trim trailing space from label
                    int llen = strlen(label);
                    while (llen > 0 && label[llen - 1] == ' ')
                        label[--llen] = 0;

                    if (prob < 0.3f || speaking)
                        continue;

                    int found_idx = -1;
                    for (int j = 0; j < NUM_LABELS; j++)
                    {
                        if (strcmp(label, label_map[j].label) == 0)
                        {
                            found_idx = j;
                            break;
                        }
                    }

                    if (found_idx == -1)
                    {
                        ESP_LOGW(TAG, "Unknown label: '%s'", label);
                        continue;
                    }

                    char filepath[64];
                    strcpy(filepath, label_map[found_idx].file);

                    if (xQueueSend(audio_queue, filepath, 0) != pdTRUE)
                    {
                        ESP_LOGW(TAG, "Audio queue full, dropping: %s", filepath);
                    }
                    else
                    {
                        ESP_LOGI(TAG, "Queued: %s (%.2f)", filepath, prob);
                    }
                }
            }
            else if (buf[i] != '\r')
            {
                if (line_pos < UART_BUF_SZ - 1)
                    line[line_pos++] = buf[i];
                else
                {
                    ESP_LOGW(TAG, "Line buffer overflow, resetting");
                    line_pos = 0;
                }
            }
        }
    }
}

/* ================= main ================= */

// void app_main(void)
// {
//     init_amp();
//     init_uart();
//     init_i2s();
//     init_spiffs();

//     audio_queue = xQueueCreate(5, sizeof(char[64]));

//     xTaskCreate(audio_task, "audio_task", 4096, NULL, 5, NULL);
//     xTaskCreate(uart_task, "uart_task", 4096, NULL, 5, NULL);

//     ESP_LOGI(TAG, "System ready");
// }

void app_main(void)
{
    init_amp();
    init_uart();
    init_i2s();
    init_spiffs();

    audio_queue = xQueueCreate(5, sizeof(char[64]));

    xTaskCreate(audio_task, "audio_task", 4096, NULL, 5, NULL);
    xTaskCreate(uart_task, "uart_task", 4096, NULL, 5, NULL);

    // test - queue a wav directly
    char test[] = "/spiffs/person.wav";
    xQueueSend(audio_queue, test, portMAX_DELAY);

    ESP_LOGI(TAG, "System ready");
}

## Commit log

2026-01-15 init PCB
    [Hansoglasses.kicad_pcb, Hansoglasses.kicad_sch, connectors.kicad_sch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]
2026-01-16 init layout
    [Hansoglasses.kicad_pcb, Hansoglasses.kicad_sch, mcu.kicad_sch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]
2026-01-16 horizontal layout ver
    [Hansoglasses.kicad_pcb]
2026-01-16 horiz layout changes
    [Hansoglasses.kicad_pcb]
2026-01-16 pcb mounting, silkscreen, started CAD
    [Hansoglasses.kicad_pcb, Hansoglasses.kicad_sch, YerraGlasses.kicad_pcb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]
2026-01-16 pcb finalized, started cad files, silkscreen
    [sunglass 2.SLDPRT]
2026-01-16 added power connector, updated cad
    [YerraGlasses.kicad_pcb, YerraGlasses.kicad_sch, connectors.kicad_sch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]
2026-01-16 production for jlc
    [YerraGlasses.kicad_pcb, YerraGlasses.kicad_sch, connectors.kicad_sch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]
2026-01-16 clean up
    [YerraGlasses.kicad_pcb, YerraGlasses.kicad_sch, connectors.kicad_sch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]
2026-01-17 updated cad
2026-01-18 cad completion prototype
    [9V BATTRAY.STL, Same_Sky_CDM-10008.step, YerraGlasses.kicad_pcb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]
2026-01-18 updated cad, code start
    [YerraGlasses.kicad_pcb, mcu.kicad_sch, speaker.kicad_sch]
2026-01-18 updated pcb cad
    [YerraGlasses.kicad_pcb, production_bom.csv, production_designators.csv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]
2026-01-21 printable cad
    [PrintableBatteryMount.step, PrintableCameraMount.step, sunglass 2.SLDPRT]
2026-01-23 cad, pcb updaates
    [BOM.csv, YerraGlasses.kicad_pcb, connectors.kicad_sch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]
2026-01-25 updated pcb order, cad
    [BOM.csv, YerraGlasses.kicad_pcb, YerraGlasses.kicad_sch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]
2026-01-30 esp32-s3 code init
2026-01-30 updated for pin outs
2026-02-28 uart to i2c
2026-03-28 i2c to uart
